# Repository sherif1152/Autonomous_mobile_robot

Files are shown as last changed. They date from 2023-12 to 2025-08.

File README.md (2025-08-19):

# Mobile Robot Project (ROS 1 – Noetic)

## Hardware Configuration

### Mechanical Structure
- **Drive System**: Differential drive mobile robot
- **Wheelbase**: 187mm (center-to-center wheel distance)
- **Wheel Specifications**: 
  - Diameter: 80mm (derived from radius = 0.04m)
  - Motorized wheels: 2
  - Encoder-equipped: Yes (330 CPR encoders)

### Sensor Placement
- **LiDAR**: Top-mounted RPLidar (specific position to be detailed)
- **Encoders**: Attached to both drive wheels
- **Additional Sensors**: LED indicator on PIN 25 for system status

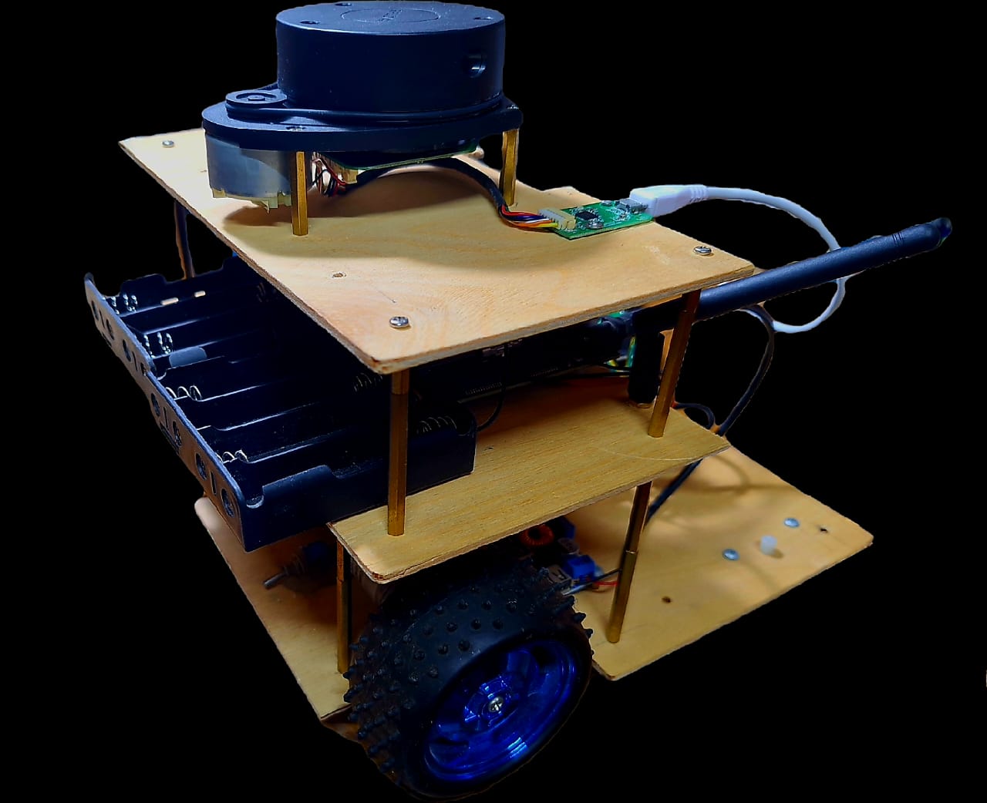
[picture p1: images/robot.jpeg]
Robot Overview - Front View

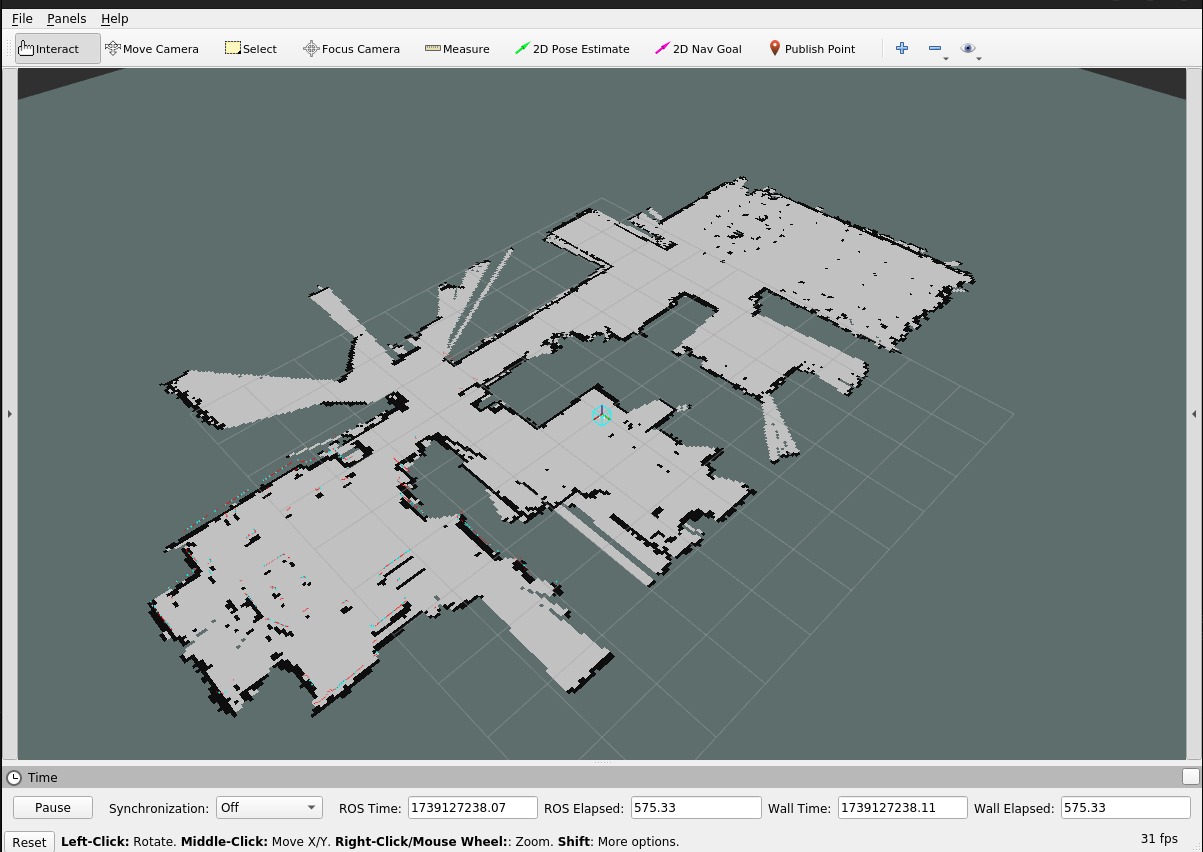
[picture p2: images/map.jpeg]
Robot CAD Model


### Key Mechanical Parameters
- **Speed Characteristics**:
  - PWM to Speed Ratio: 0.00335 (speed-to-pwm ratio for motor control)
  - Configurable maximum speed limits
- **Construction**: Rigid chassis with precision-mounted motors for accurate odometry

## Electrical Components & Pin Connections

### Core Computing Units
- **Main Computer**: NVIDIA Jetson Nano
  - Power Supply: 5V/4A
  - Network: WiFi/Ethernet (192.168.1.117)
- **Microcontroller**: Raspberry Pi Pico
  - Operating Voltage: 3.3V
  - Connected via USB to Jetson Nano

### Motor System
- **Motors**: 2x DC Motors with Encoders
  - Operating Voltage: 12V
  - Encoder Resolution: 330 CPR
- **Motor Driver**: L298N Dual H-Bridge
  - Logic Voltage: 5V
  - Motor Supply: 12V

### Sensors
- **LiDAR**: RPLidar A1
  - Interface: USB
  - Power: 5V
- **Encoders**: Quadrature Encoders
  - Resolution: 330 CPR
  - Operating Voltage: 3.3V

### Pin Connection Table

| Component | Pico Pin | Function |
|---|---|---|
| Left Motor A | GPIO 2 | PWM Control |
| Left Motor B | GPIO 3 | Direction |
| Right Motor A| GPIO 4 | PWM Control |
| Right Motor B| GPIO 5 | Direction |
| Left Encoder A| GPIO 6  | Encoder Phase |
| Left Encoder B| GPIO 7  | Encoder Phase |
| Right Encoder A| GPIO 8 | Encoder Phase |
| Right Encoder B| GPIO 9 | Encoder Phase |
| Status LED | GPIO 25  | System Status |

### Power Distribution
- **Main Battery**: 4S LiPo Battery
  - Voltage: 14.8V nominal (16.8V fully charged)
  - Powers: Motors directly, converted for electronics
- **Voltage Regulation**:
  - Buck Converter: 14.8V → 5V @ 5A
    - Primary output: Jetson Nano power supply
    - Efficiency: >90%

## Software Setup

### Development Environment Setup

#### 1. Jetson Nano Configuration

* **Operating System**: Ubuntu 20.04 LTS
* **ROS Version**: ROS 1 Noetic
* **Network Configuration**:

  ```bash
  # Add to /etc/hosts
  192.168.1.117   jet 
  192.168.1.110   pc
  ```

#### 2. SSH Connection Setup

```bash
# From development PC
ssh jetson@192.168.1.117

# Test connection
ping jet
ping pc

# Set ROS environment variables
export ROS_MASTER_URI=http://jet:11311
export ROS_HOSTNAME=jet
```

*(Add those to `~/.bashrc` for persistence.)*

#### 3. ROS 1 Workspace Setup

```bash
# Create catkin workspace
mkdir -p ~/catkin_ws/src
cd ~/catkin_ws
catkin_make

# Source workspace
source devel/setup.bash
```

#### 4. Raspberry Pi Pico Setup
```bash
# Install serial communication tools
sudo apt install python3-serial

# Verify Pico connection
ls /dev/ttyACM*
```

## Debug Steps

#### 1. Communication Check

```bash
ls -l /dev/ttyACM0
screen /dev/ttyACM0 115200
```

#### 2. ROS 1 Network Check

```bash
# Test ROS 1 communication
rostopic list
rosnode list

# Check topic data
rostopic echo /cmd_vel
rostopic echo /odom
```

---

## Packages and Dependencies

### Core ROS 1 Packages

* **robot\_core**: hardware interface + motor control + odometry
* **robot\_description**: URDF, meshes, TFs, visualization

### External Dependencies

#### ROS 1 Packages

```bash
# Install required ROS 1 packages
sudo apt install ros-noetic-navigation \
                 ros-noetic-gmapping \
                 ros-noetic-amcl \
                 ros-noetic-rplidar-ros \
                 ros-noetic-joint-state-publisher \
                 ros-noetic-robot-state-publisher \
                 ros-noetic-tf2-tools
```

#### Python Dependencies

```bash
pip3 install numpy pyserial transforms3d scipy
```

### Version Requirements

* **ROS 1**: Noetic
* **Python**: >= 3.8
* **OpenCV**: >= 4.2

---

## How to Run & Debug

### Initial Setup

#### 1. Power Up Sequence
1. Connect 4S LiPo battery (check voltage > 14.4V)
2. Wait for Jetson Nano boot sequence (~30s)
3. Verify Pico connection:
```bash
ls -l /dev/ttyACM0
sudo chmod 666 /dev/ttyACM0  # If permission denied
```

#### 2. Network Configuration
```bash
# Verify network setup
ip addr show
# Should show eth0 or wlan0 with IP 192.168.1.117

# Test PC connection
ping pc
```

### Launch Sequence

#### 1. Core System

```bash
# Terminal 1: Start ROS master
roscore
```

```bash
# Terminal 2: Launch core robot bringup
roslaunch robot_core bringup.launch
```

#### 2. Sensors

```bash
# Terminal 3: Launch LiDAR
roslaunch rplidar_ros rplidar.launch
```

#### 3. Navigation Stack

```bash
# Terminal 4: Start navigation
roslaunch robot_navigation move_base.launch
```

---

### Common Debug Procedures

#### 1. Motor Control Debug

```bash
rostopic pub /cmd_vel geometry_msgs/Twist "linear:
  x: 0.1
  y: 0.0
  z: 0.0
angular:
  x: 0.0
  y: 0.0
  z: 0.0"
```

#### 2. Encoder Feedback

```bash
rostopic echo /wheel_ticks
rostopic echo /odom
```

#### 3. TF Tree

```bash
rosrun tf view_frames
evince frames.pdf
```

---

### Troubleshooting

#### Common Issues
1. **Motor Not Responding**
   - Check motor power (14.8V line)
   - Verify PWM signals using oscilloscope
   - Check encoder connections

2. **Odometry Drift**
   - Calibrate wheel radius parameter
   - Verify encoder resolution setting
   - Check wheel slippage

3. **Navigation Issues**
   - Verify TF tree:
   ```bash
    rosrun tf view_frames
    evince frames.pdf
   ```
   - Check costmap updates:
   ```bash
    rostopic echo /move_base/local_costmap/costmap
    rostopic echo /move_base/global_costmap/costmap
   ```

> Note: Always check battery voltage under load - system may behave erratically at voltages below 14.4V

## References & Credits

### External Projects
- **Nox Robot Project**
  - Source: [Nox_robot](https://github.com/RBinsonB/Nox_robot)
  - Author: RBinsonB
  - License: MIT
  - Used for: Reference design and inspiration for differential drive implementation
  - Key components adapted:
    - Motor control architecture
    - Odometry calculation methods
    - ROS 1 node structure

### Hardware References
- RPLidar A1 Manual: [Slamtec Documentation](https://www.slamtec.com/en/Support#rplidar-a-series)
- Raspberry Pi Pico Datasheet: [Raspberry Pi Documentation](https://datasheets.raspberrypi.com/pico/pico-datasheet.pdf)
- L298N Motor Driver: [Component Datasheet](http://www.st.com/resource/en/datasheet/l298.pdf)

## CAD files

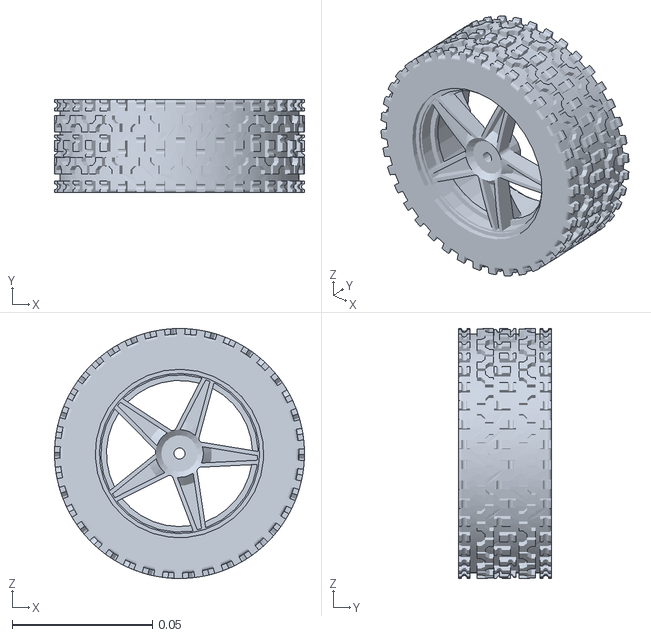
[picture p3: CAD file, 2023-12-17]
src/description_pkg/meshes/right_wheel.STL
0.089 x 0.033 x 0.089

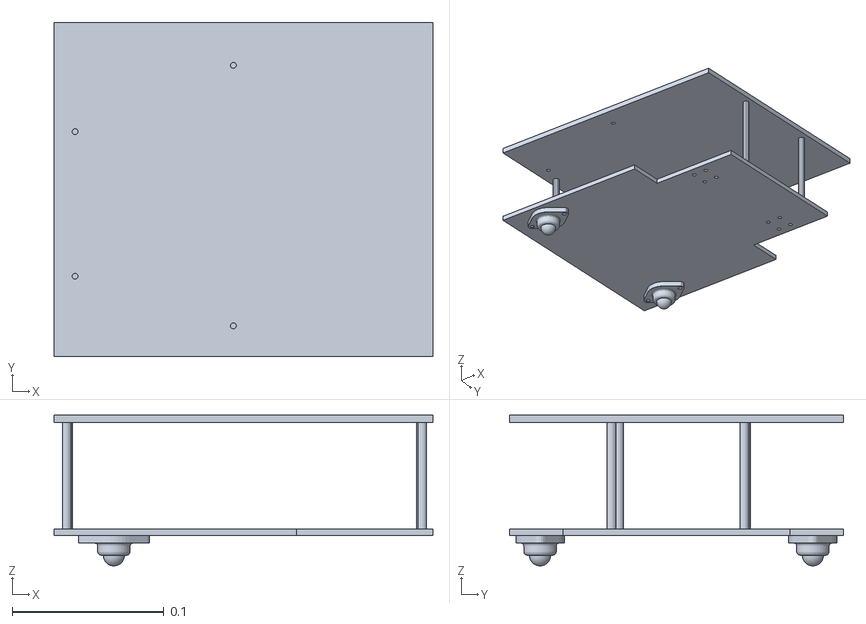
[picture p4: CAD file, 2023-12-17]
src/description_pkg/meshes/base_link.STL
0.25 x 0.22 x 0.0995

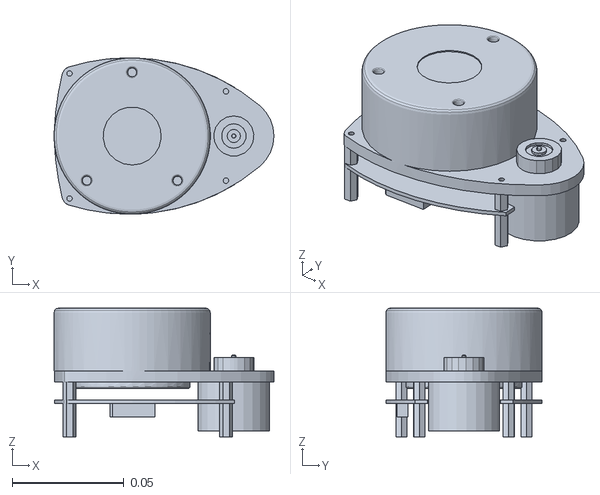
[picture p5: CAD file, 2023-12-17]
src/description_pkg/meshes/lidar.STL
0.0985 x 0.07 x 0.0577

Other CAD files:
src/description_pkg/meshes/left_wheel.STL

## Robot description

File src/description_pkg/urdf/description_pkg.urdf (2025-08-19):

<?xml version="1.0" encoding="utf-8"?>
<!-- This URDF was automatically created by SolidWorks to URDF Exporter! Originally created by Stephen Brawner (brawner@gmail.com) 
     Commit Version: 1.6.0-4-g7f85cfe  Build Version: 1.6.7995.38578
     For more information, please see http://wiki.ros.org/sw_urdf_exporter -->
<robot name="description_pkg">

  <link name="base_link">
    <inertial>
      <origin xyz="0.0034114 2.3578E-05 0.037822" rpy="0 0 0" />
      <mass value="0.51342" />
      <inertia ixx="0.0018609" ixy="1.3812E-07" ixz="9.9607E-18" iyy="0.0024947" iyz="3.8719E-18" izz="0.0043499" />
    </inertial>
    <visual>
      <origin xyz="0 0 0" rpy="0 0 0" />
      <geometry>
        <mesh filename="package://description_pkg/meshes/base_link.STL" />
      </geometry>
      <material name="">
        <color rgba="0.79216 0.81961 0.93333 1" />
      </material>
    </visual>
    <collision>
      <origin xyz="0 0 0" rpy="0 0 0" />
      <geometry>
        <mesh filename="package://description_pkg/meshes/base_link.STL" />
      </geometry>
    </collision>
  </link>
  <link name="right_wheel">
    <inertial>
      <origin xyz="-3.9565E-09 0.016121 1.5411E-09" rpy="0 0 0" />
      <mass value="0.12113" />
      <inertia ixx="8.7E-05" ixy="1.2167E-11" ixz="-9.7666E-14" iyy="0.00015319" iyz="-4.7353E-12" izz="8.7E-05" />
    </inertial>
    <visual>
      <origin xyz="0 0 0" rpy="0 0 0" />
      <geometry>
        <mesh filename="package://description_pkg/meshes/right_wheel.STL" />
      </geometry>
      <material name="">
        <color rgba="0.50196 0.50196 0.50196 1" />
      </material>
    </visual>
    <collision>
      <origin xyz="0 0 0" rpy="0 0 0" />
      <geometry>
        <mesh filename="package://description_pkg/meshes/right_wheel.STL" />
      </geometry>
    </collision>
  </link>
  <joint name="joint_right_wheel" type="continuous">
    <origin xyz="0.0904581836051767 -0.1095 0.02" rpy="0 0 0" />
    <parent link="base_link" />
    <child link="right_wheel" />
    <axis xyz="0 1 0" />
  </joint>
  <link name="left_wheel">
    <inertial>
      <origin xyz="4.246E-09 -0.016121 6.0085E-13" rpy="0 0 0" />
      <mass value="0.12113" />
      <inertia ixx="8.7E-05" ixy="1.3056E-11" ixz="1.3227E-13" iyy="0.00015319" iyz="-1.7583E-15" izz="8.7E-05" />
    </inertial>
    <visual>
      <origin xyz="0 0 0" rpy="0 0 0" />
      <geometry>
        <mesh filename="package://description_pkg/meshes/left_wheel.STL" />
      </geometry>
      <material name="">
        <color rgba="0.50196 0.50196 0.50196 1" />
      </material>
    </visual>
    <collision>
      <origin xyz="0 0 0" rpy="0 0 0" />
      <geometry>
        <mesh filename="package://description_pkg/meshes/left_wheel.STL" />
      </geometry>
    </collision>
  </link>
  <joint name="joint_left_wheel" type="continuous">
    <origin xyz="0.0904581836051742 0.109499999999999 0.0200000000000001" rpy="0 0 0" />
    <parent link="base_link" />
    <child link="left_wheel" />
    <axis xyz="0 1 0" />
  </joint>
  <link name="laser">
    <inertial>
      <origin xyz="0.0067683 -0.00020768 -0.022438" rpy="0 0 0" />
      <mass value="0.3304" />
      <inertia ixx="0.00061474" ixy="-8.0027E-07" ixz="0.00015819" iyy="0.0009605" iyz="-3.096E-06" izz="0.0010981" />
    </inertial>
    <visual>
      <origin xyz="0 0 0" rpy="0 0 0" />
      <geometry>
        <mesh filename="package://description_pkg/meshes/lidar.STL" />
      </geometry>
      <material name="">
        <color rgba="0.29804 0.29804 0.29804 1" />
      </material>
    </visual>
    <collision>
      <origin xyz="0 0 0" rpy="0 0 0" />
      <geometry>
        <mesh filename="package://description_pkg/meshes/lidar.STL" />
      </geometry>
    </collision>
  </link>
  <joint name="joint_lidar" type="fixed">
    <origin xyz="0.0782512924534475 0.000163224895598668 0.1327" rpy="0 0 0" />
    <parent link="base_link" />
    <child link="laser" />
    <axis xyz="0 0 0" />
  </joint>
  
  <!-- <gazebo>
   <plugin name="differential_drive_controller" filename="libgazebo_ros_diff_drive.so">
       <updateRate>30.0</updateRate>
      <commandTopic>cmd_vel</commandTopic>
      <odometryTopic>odom</odometryTopic>
      <odometryFrame>odom</odometryFrame>
      <odometrySource>world</odometrySource>
      <publishOdomTF>true</publishOdomTF>
      <robotBaseFrame>base_link</robotBaseFrame>
      <publishWheelTF>false</publishWheelTF>
      <publishTf>true</publishTf>
      <publishWheelJointState>true</publishWheelJointState>
      <legacyMode>false</legacyMode>
      <updateRate>30</updateRate>
      <leftJoint>joint_left_wheel</leftJoint>
      <rightJoint>joint_right_wheel</rightJoint>
      <wheelSeparation>0.15</wheelSeparation>
      <wheelDiameter>0.085</wheelDiameter>
      <wheelAcceleration>10</wheelAcceleration>
      <wheelTorque>20</wheelTorque>
      <rosDebugLevel>na</rosDebugLevel>
    </plugin>
  </gazebo>
  
     <!- - LIDER - ->
    <gazebo reference="lidar">
        <sensor type="ray" name="head_hokuyo_sensor">
            <pose>0 0 0 0 0 0</pose>
            <visualize>false</visualize>
            <update_rate>40</update_rate>
            <ray>
                <scan>
                    <horizontal>
                        <samples>720</samples>
                        <resolution>1</resolution>
                        <min_angle>-1.570796</min_angle>
                        <max_angle>1.570796</max_angle>
                    </horizontal>
                </scan>
                <range>
                    <min>0.10</min>
                    <max>30.0</max>
                    <resolution>0.01</resolution>
                </range>
                <noise>
                    <type>gaussian</type>
                    <!- - Noise parameters based on published spec for Hokuyo laser
                        achieving "+-30mm" accuracy at range < 10m.  A mean of 0.0m and
                        stddev of 0.01m will put 99.7% of samples within 0.03m of the true
                        reading. - ->
                    <mean>0.0</mean>
                    <stddev>0.01</stddev>
                </noise>
            </ray>
            <plugin name="gazebo_ros_head_hokuyo_controller" filename="libgazebo_ros_laser.so">
                <topicName>/scan</topicName>
                <frameName>lidar</frameName>
            </plugin>
        </sensor>
    </gazebo> -->
  
  
</robot>

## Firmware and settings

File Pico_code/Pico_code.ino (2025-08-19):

#include <PID_v1.h>
#include <ros.h>
#include <std_msgs/String.h>
#include <geometry_msgs/Vector3Stamped.h>
#include <geometry_msgs/Twist.h>
#include <ros/time.h>
 
//initializing all the variables
#define LOOPTIME                      100     //Looptime in millisecond
const byte noCommLoopMax = 10;                //number of main loops the robot will execute without communication before stopping
uint16_t noCommLoops = 0;                 //main loop without communication counter

double speed_cmd_left2 = 0;      

const int PIN_ENCOD_A_MOTOR_LEFT = 15;               //A channel for encoder of left motor                    
const int PIN_ENCOD_B_MOTOR_LEFT = 14;               //B channel for encoder of left motor

const int PIN_ENCOD_A_MOTOR_RIGHT = 16;              //A channel for encoder of right motor         
const int PIN_ENCOD_B_MOTOR_RIGHT = 17;              //B channel for encoder of right motor 

const int PIN_SIDE_LIGHT_LED = 25;                  //Side light blinking led pin

unsigned long lastMilli = 0;

//l298n driver pin configuration
const int A_motor_speed = 2;
const int A_motor_1 = 4;
const int A_motor_2 = 3;  

const int B_motor_speed = 6;
const int B_motor_1 = 8;
const int B_motor_2 = 7; 

//--- Robot-specific constants ---
const double radius = 0.04;                   //Wheel radius, in m
const double wheelbase = 0.187;               //Wheelbase, in m
const double encoder_cpr = 330;               //Encoder ticks or counts per rotation
const double speed_to_pwm_ratio = 0.00335;    //Ratio to convert speed (in m/s) to PWM value. It was obtained by plotting the wheel speed in relation to the PWM motor command (the value is the slope of the linear function).
const double min_speed_cmd = 0.1273;          //(min_speed_cmd/speed_to_pwm_ratio) is the minimum command value needed for the motor to start moving. This value was obtained by plotting the wheel speed in relation to the PWM motor command (the value is the constant of the linear function).

double speed_req = 0;                         //Desired linear speed for the robot, in m/s
double angular_speed_req = 0;                 //Desired angular speed for the robot, in rad/s

double speed_req_left = 0;                    //Desired speed for left wheel in m/s
double speed_act_left = 0;                    //Actual speed for left wheel in m/s
double speed_cmd_left = 0;                    //Command speed for left wheel in m/s 

double speed_req_right = 0;                   //Desired speed for right wheel in m/s
double speed_act_right = 0;                   //Actual speed for right wheel in m/s
double speed_cmd_right = 0;                   //Command speed for right wheel in m/s 
                        
const double max_speed = 8.5;                 //Max speed in m/s

int PWM_leftMotor = 0;                     //PWM command for left motor
int PWM_rightMotor = 0;                    //PWM command for right motor 
                                                      
// PID Parameters
const double PID_left_param[] = { 0.3, 0.015, 0.15 }; //Respectively Kp, Ki and Kd for left motor PID
const double PID_right_param[] = { 0.3, 0.015, 0.15 }; //Respectively Kp, Ki and Kd for right motor PID

volatile float pos_left = 0;       //Left motor encoder position
volatile float pos_right = 0;      //Right motor encoder position

PID PID_leftMotor(&speed_act_left, &speed_cmd_left, &speed_req_left, PID_left_param[0], PID_left_param[1], PID_left_param[2], DIRECT);          //Setting up the PID for left motor
PID PID_rightMotor(&speed_act_right, &speed_cmd_right, &speed_req_right, PID_right_param[0], PID_right_param[1], PID_right_param[2], DIRECT);   //Setting up the PID for right motor
  
ros::NodeHandle nh;

//function that will be called when receiving command from host
void handle_cmd (const geometry_msgs::Twist& cmd_vel) {
  noCommLoops = 0;                                                  //Reset the counter for number of main loops without communication
  
  speed_req = cmd_vel.linear.x;                                     //Extract the commanded linear speed from the message

  angular_speed_req = cmd_vel.angular.z;                            //Extract the commanded angular speed from the message
  
  speed_req_left = speed_req + angular_speed_req*(wheelbase/2);     //Calculate the required speed for the left motor to comply with commanded linear and angular speeds
  speed_req_right = speed_req - angular_speed_req*(wheelbase/2);    //Calculate the required speed for the right motor to comply with commanded linear and angular speeds
}

ros::Subscriber<geometry_msgs::Twist> cmd_vel("cmd_vel", handle_cmd);   //create a subscriber to ROS topic for velocity commands (will execute "handle_cmd" function when receiving data)
geometry_msgs::Vector3Stamped speed_msg;                                //create a "speed_msg" ROS message
ros::Publisher speed_pub("speed", &speed_msg);                          //create a publisher to ROS topic "speed" using the "speed_msg" type



//__________________________________________________________________________

void setup() {

  
  pinMode(PIN_SIDE_LIGHT_LED, OUTPUT);      //set pin for side light leds as output
  analogWrite(PIN_SIDE_LIGHT_LED, 255);     //light up side lights

  //Setting motors pin as an output
      //motor A
  pinMode(A_motor_speed, OUTPUT);
  pinMode(A_motor_1, OUTPUT);
  pinMode(A_motor_2, OUTPUT);
      //motor B
  pinMode(B_motor_speed, OUTPUT);
  pinMode(B_motor_1, OUTPUT);
  pinMode(B_motor_2, OUTPUT);
 
  nh.initNode();                            //init ROS node
  nh.getHardware()->setBaud(115200);         //set baud for ROS serial communication
  nh.subscribe(cmd_vel);                    //suscribe to ROS topic for velocity commands
  nh.advertise(speed_pub);                  //prepare to publish speed in ROS topic
 
  //setting PID parameters
  PID_leftMotor.SetSampleTime(95);
  PID_rightMotor.SetSampleTime(95);
  PID_leftMotor.SetOutputLimits(-max_speed, max_speed);
  PID_rightMotor.SetOutputLimits(-max_speed, max_speed);
  PID_leftMotor.SetMode(AUTOMATIC);
  PID_rightMotor.SetMode(AUTOMATIC);
    
  // Define the rotary encoder for left motor
  pinMode(PIN_ENCOD_A_MOTOR_LEFT, INPUT); 
  pinMode(PIN_ENCOD_B_MOTOR_LEFT, INPUT); 
  digitalWrite(PIN_ENCOD_A_MOTOR_LEFT, HIGH);                // turn on pullup resistor
  digitalWrite(PIN_ENCOD_B_MOTOR_LEFT, HIGH);
  attachInterrupt(PIN_ENCOD_A_MOTOR_LEFT, encoderLeftMotor, RISING);

  // Define the rotary encoder for right motor
  pinMode(PIN_ENCOD_A_MOTOR_RIGHT, INPUT); 
  pinMode(PIN_ENCOD_B_MOTOR_RIGHT, INPUT); 
  digitalWrite(PIN_ENCOD_A_MOTOR_RIGHT, HIGH);                // turn on pullup resistor
  digitalWrite(PIN_ENCOD_B_MOTOR_RIGHT, HIGH);
  attachInterrupt(PIN_ENCOD_A_MOTOR_RIGHT, encoderRightMotor, RISING);
}
const int lightIncNumber = 30;                                                                                                                                       //Number of lightIncrements for side light blinking
int lightInc = 0;                                                                                                                                                    //Init increment for side light blinking
int lightValue [lightIncNumber]= { 10, 40, 80, 160, 255, 255, 255, 255, 255, 255, 255, 255, 255, 255, 255, 255, 255, 255, 160, 80, 40, 10, 0, 0, 0, 0, 0, 0, 0, 0 }; //side light increment values
int lightValueNoComm [25]= { 255, 0, 255, 0, 255, 0, 0, 0, 0, 0, 0, 0, 0, 0, 0, 0, 0, 0, 0, 0, 0, 0, 0, 0, 0 }; //side light increment values
int lightT = 0; //init light period
//_________________________________________________________________________

void loop() {
  nh.spinOnce();
  if((millis()-lastMilli) >= LOOPTIME)   
  {                                                                           // enter timed loop
    lastMilli = millis();
    
    if (!nh.connected()){
      analogWrite(PIN_SIDE_LIGHT_LED, lightValueNoComm[lightInc]);
      lightInc=lightInc+1;
      if (lightInc >= 25){
        lightInc=0;
      }
    }
    else{
      analogWrite(PIN_SIDE_LIGHT_LED, 255);
      lightT = 3000 - ((2625/max_speed)*((abs(speed_req_left)+abs(speed_req_right))/2));
      lightInc=lightInc+(30/(lightT/LOOPTIME));
      if (lightInc >= lightIncNumber){
        lightInc=0;
      }
    }
    
    
    if (abs(pos_left) < 5){                                                   //Avoid taking in account small disturbances
      speed_act_left = 0;
    }
    else {
      speed_act_left=((pos_left/encoder_cpr)*2*PI)*(1000/LOOPTIME)*radius;           // calculate speed of left wheel
    }
    
    if (abs(pos_right) < 5){                                                  //Avoid taking in account small disturbances
      speed_act_right = 0;
    }
    else {
    speed_act_right=((pos_right/encoder_cpr)*2*PI)*(1000/LOOPTIME)*radius;          // calculate speed of right wheel
    }
    
    pos_left = 0;
    pos_right = 0;

    speed_cmd_left = constrain(speed_cmd_left, -max_speed, max_speed);
    PID_leftMotor.Compute();                                                 
    // compute PWM value for left motor. Check constant definition comments for more information.
    PWM_leftMotor = constrain(((speed_req_left+sgn(speed_req_left)*min_speed_cmd)/speed_to_pwm_ratio) + (speed_cmd_left/speed_to_pwm_ratio), -115, 100); //
    
    if (noCommLoops >= noCommLoopMax || speed_req_left == 0) {                   //Stopping if too much time without command
      analogWrite(A_motor_speed , 0);
      digitalWrite(A_motor_1 , 0);
      digitalWrite(A_motor_2 , 0);
    }
    else if (PWM_leftMotor > 0){                          //Going forward
      analogWrite(A_motor_speed , abs(PWM_leftMotor));
      digitalWrite(A_motor_1 , 1);
      digitalWrite(A_motor_2 , 0);
    }
    else {                                               //Going backward
      analogWrite(A_motor_speed , abs(PWM_leftMotor));
      digitalWrite(A_motor_1 , 0);
      digitalWrite(A_motor_2 , 1);
    }
    
    speed_cmd_right = constrain(speed_cmd_right, -max_speed, max_speed);    
    PID_rightMotor.Compute();                                                 
    // compute PWM value for right motor. Check constant definition comments for more information.
    PWM_rightMotor = constrain(((speed_req_right+sgn(speed_req_right)*min_speed_cmd)/speed_to_pwm_ratio) + (speed_cmd_right/speed_to_pwm_ratio), -110, 110); // 

    if (noCommLoops >= noCommLoopMax || speed_req_right == 0) {                   //Stopping if too much time without command
      analogWrite(B_motor_speed , 0);
      digitalWrite(B_motor_1 , 0);
      digitalWrite(B_motor_2 , 1);
    }
    else if (PWM_rightMotor > 0){                         //Going forward
      analogWrite(B_motor_speed , abs(PWM_rightMotor));
      digitalWrite(B_motor_1 , 1);
      digitalWrite(B_motor_2 , 0);
    }
    else {                                                //Going backward
      analogWrite(B_motor_speed , abs(PWM_rightMotor));
      digitalWrite(B_motor_1 , 0);
      digitalWrite(B_motor_2 , 1);
    }

    if((millis()-lastMilli) >= LOOPTIME){         //write an error if execution time of the loop in longer than the specified looptime
      Serial.println(" TOO LONG ");
    }

    noCommLoops++;
    if (noCommLoops == 65535){
      noCommLoops = noCommLoopMax;
    }
    
    publishSpeed(10);   //Publish odometry on ROS topic
  }
 }

//Publish function for odometry, uses a vector type message to send the data (message type is not meant for that but that's easier than creating a specific message type)
void publishSpeed(double time) {
  speed_msg.header.stamp = nh.now();      //timestamp for odometry data
  speed_msg.vector.x = speed_act_left;    //left wheel speed (in m/s)
  speed_msg.vector.y = speed_act_right;   //right wheel speed (in m/s)
  speed_msg.vector.z = time/100;         //looptime, should be the same as specified in LOOPTIME (in s)
  speed_pub.publish(&speed_msg);
  nh.spinOnce();
  nh.loginfo("Publishing odometry");
}

void encoderLeftMotor() {
  if (digitalRead(PIN_ENCOD_A_MOTOR_LEFT) == digitalRead(PIN_ENCOD_B_MOTOR_LEFT)) pos_left--;
  else pos_left++;  
}

void encoderRightMotor() {
  if (digitalRead(PIN_ENCOD_A_MOTOR_RIGHT) == digitalRead(PIN_ENCOD_B_MOTOR_RIGHT)) pos_right++;
  else pos_right--;
}


template <typename T> int sgn(T val) {
    return (T(0) < val) - (val < T(0));
}

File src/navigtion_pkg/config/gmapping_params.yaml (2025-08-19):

	map_update_interval: 10.0
	maxUrange: 5.0
	maxRange: 8.0
	sigma: 0.05
	kernelSize: 1
	lstep: 0.05
	astep: 0.05
	iterations: 5
	lsigma: 0.075
	ogain: 3.0
	lskip: 0
	minimumScore: 0.0
	srr: 0.1
	srt: 0.2
	str: 0.1
	stt: 0.2
	linearUpdate: 0.4
	angularUpdate: 0.2
	temporalUpdate: 10.0
	resampleThreshold: 0.4
	particles: 60
	xmin: -10.0
	ymin: -10.0
	xmax: 10.0
	ymax: 10.0
	delta: 0.05
	llsamplerange: 0.01
	llsamplestep: 0.01
	lasamplerange: 0.005
	lasamplestep: 0.005

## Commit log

2023-11-15 Uploading Arduino code file
2023-11-15 Update Arduino.ino after customization
    Adding the L298n motor driver in the code
    Configure the code to be uploaded on Arduino UNO
2023-12-17 Adding the description pkg and (first.launch) launch file that connects the Arduino to start conntrolling the robot with teleop_keyboard
    [base_link.STL, description_pkg.csv, description_pkg.urdf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]
2025-08-19 Add the Robot Pkgs
    [base_link.STL, description_pkg.csv, description_pkg.urdf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]
